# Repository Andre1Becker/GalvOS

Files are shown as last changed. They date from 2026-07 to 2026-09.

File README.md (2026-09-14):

# GalvOS








---

## What Is GalvOS?

GalvOS replaces the original control board of an RGB galvo laser projector (specifically the Mikoy 5W) with an ESP32-S3-based system. The result is a firmware platform that is more capable, fully open, and frankly more fun to work with than whatever the OEM shipped.

The origin story: the stock firmware couldn't dim the laser — it was full-brightness or nothing. What started as a quick bug investigation turned into a complete hardware and firmware replacement. Classic "Well, that escalated quickly..." moment.

**Key capabilities:**

- 16-bit galvo DAC (vs. OEM 12-bit) via SPI DAC8562
- Browser-based WebUI — no app install, works from any phone or desktop
- DMX-512, Art-Net, sACN/E1.31, and OSC input; Ether Dream and Helios (network) DAC protocols
- ILDA file playback from SD card
- Per-point laser modulation with full RGB PWM control
- BPM-synced show engine: global tempo clock (Tap/DMX/Manual), preset sequencer, and an 8-slot modulation matrix (LFO/Noise/Envelope/Step-Sequencer → any live pattern parameter)
- Watchdog, scan-command activity and E-stop interfaces — [safety qualification remains open](hardware/reviews/2026-09-14-shutdown-boundary.md)
- Point optimizer pipeline with adaptive density, S-curve blanking, and ringing compensation
- Camera-in-the-loop auto-tuning of optimizer parameters via a companion Python tool (see [Chapter 6](docs/06-camera-autotuning.md))
- Community Presets — browse, download, and activate GitHub-hosted preset bundles straight from the WebUI
- Temperature monitoring (up to 5× DS18B20 sensors)

---

## Full Feature List

Yes, all of this is real, and yes, it's all running on a 6 Freedom Money ($) microcontroller.
(That exclude all the other components you need - but hey, sounds much more impressive this way:-) )

### Output & Rendering

| Feature | What it does |
| --- | --- |
| 16-bit galvo DAC (DAC8562) | 4× the resolution of the OEM's 12-bit — lines that were jagged are now just... lines. |
| 9-stage point optimizer pipeline | Turns "draw a hexagon" into a stream the mirrors can physically survive — corner dwell, blanking, velocity/acceleration clamp, ZV ringing compensation. |
| 8 optimizer profiles (Vector, Smooth, Waves, Wireframe, MultiObject, Particles, Trails, Text) | One-size-fits-all optimizer settings don't exist, so pick per preset class instead. Auto-switches with the active preset. |
| Curvature-adaptive resampling | Spends points where the path actually bends and thins them out on straight runs, instead of pretending every millimetre is equally interesting. |
| Jump-order optimization (nearest-neighbour + 2-opt) | Reorders which segment gets drawn when, so the beam stops zigzagging across the canvas with the laser off. |
| Optimizer live telemetry | Lit/blank counts, truncated points, jump distance, which budget stage fired — tuning with numbers instead of vibes. |
| Smart Defaults button | Computes sane optimizer parameters from your kpps and frame budget. For when guessing sliders gets old. |
| Adjustable galvo sample rate (12–60 kpps) with Autotune | Binary-searches the highest rate your hardware handles before it starts buffering complaints. |
| CIE 1931 gamma correction | γ≈2.2 so "50% brightness" actually looks like 50% brightness to your eyeballs, not to a linear sensor. |
| Projection zone clipping | Draw a polygon, laser respects it. Points outside get blanked instead of redecorating your neighbor's wall. |
| Grid warp (keystone / surface correction) | Up to 5×5 control points to bend the image onto an off-axis or non-flat wall — corrects everything the projector draws, presets to ILDA files. |
| Brightness compensation grid | Same grid editor aimed at photons: evens out the exposure falloff you get from throw distance and angle. |
| Model-based inverse filter | Per-axis deconvolution of the galvo's measured resonance, applied to every point — the mirrors track the commanded path instead of ringing around it. |
| Output pre-scale | Shrinks the image proportionally so extreme corners stay in the galvo's linear range, instead of being flattened by the DAC clamp. |

### Patterns & Effects

| Feature | What it does |
| --- | --- |
| Built-in preset library (Geometry, Waves, 3D, Scenes, math curves) | A whole gallery of shapes so you don't have to parametrize a Lissajous curve at 2 AM. |
| Auto-rotation (independent X/Y/Z) + static rotation offset | Spin any pattern on any axis, at its own speed, because static geometry is for cowards. |
| 7 color animation modes (Gradient, Chase, Strobe, Pulse, Twinkle, Flip, Seg) | Layer a light show on top of any preset's own color without touching its code. |
| Points-Only Mode | Turns any pattern into a dot cloud with configurable fade-in/out and fade direction — instant particle show. |
| True Kaleidoscope (dihedral mirror-fold, 2/4/6-fold) + Radial Repeat mode & Mirror | Symmetric multiplication of whatever's on screen, because one hexagon is never enough. |
| Global BPM clock (Manual / Tap Tempo / DMX) | The whole show keeps a beat — priority DMX > Tap > Manual, with a big satisfying TAP button. |
| Preset Sequencer | A BPM-synced set list: walk presets step by step, beat-quantized, with optional blank transitions. Never auto-starts on boot — Class 4 lasers don't get autoplay. |
| Modulation engine (8 slots × 16 bindings) | LFOs, noise, multi-point envelopes, and step sequencers routed onto scale, rotation, hue, speed, density... Patterns that breathe on their own. |
| Modular modules: Camera, Duplicator, Spatial Noise, Dotter | Self-registering firmware modules that add 3D camera moves, frame cloning (grid/radial/spiral), organic wobble, and dot scatter — the UI discovers them automatically. |
| Freehand Paint tab | Draw with your finger or mouse, project it as vectors. Shape tools, mirror modes, undo/redo, and text insertion included for people who can't draw circles. |
| Laser Welding effect | A travelling torch head with a fading afterglow and ballistic sparks, rendered from the same Paint canvas. Pure theatre, and worth it. |
| SVG import | Load a vector drawing in the browser, simplify it to fit the point budget, and project it. Files can live on the SD card too. |
| Per-segment colors | Give a polygon or star a different color per edge, with an optional travelling animation. |
| Laser Text mode | 3 fonts, 10 animations (scroll, bounce, typewriter, Star Wars crawl,...), up to 127 characters. |
| Countdown timer with laser payoff | Set a timer, and when it hits zero: show text or fire off an ILDA file. Genuinely useful for events. |
| Community Presets (GitHub-hosted) | Browse a shared preset library straight from GitHub in the WebUI, download to the device, activate with one tap — each bundle carries a full optimizer tuning plus playback params. Now the internet can pick your colors too. |
| Community Preset Builder | Offline browser tool ([`community-presets/builder.html`](community-presets/builder.html)) for creating those bundles — for people who'd rather drag sliders than write C++. Advanced Mode even has a point/curve editor that exports C++ snippets for new built-in presets. |

### Control Inputs

| Feature | What it does |
| --- | --- |
| DMX-512 input (MAX485, 25 channels) | Talks to any real lighting desk like a grown-up fixture. |
| Art-Net input | DMX over Ethernet/Wi-Fi for the desk-less crowd. |
| sACN / E1.31 input | The standards-blessed way to do DMX over IP multicast. Same channel map, lowest priority of the three DMX-shaped sources. |
| OSC input | `/galvos/*` on UDP 9000 — preset, color, speed, brightness, and override from TouchOSC & friends. |
| Ether Dream protocol receiver | Laser software that speaks Ether Dream can stream point data straight to the projector. |
| Helios DAC network emulation | Helios point-stream framing over TCP 7768. The USB variant is not implemented (TinyUSB vendor class vs. the USB-CDC console). |
| Live software DMX console (WebUI) | 25 sliders, no physical desk required, with instant test patterns (red circle, rainbow). |
| WebUI override priority | WebUI wins over DMX on demand — for when you need to grab manual control mid-show. |
| Master dimmer (WebUI + DMX CH1 combined) | One dial to rule the overall brightness, regardless of source. |

### Storage & Playback

| Feature | What it does |
| --- | --- |
| ILDA file playback from SD card | Plays the industry-standard laser show format straight off a memory card — subfolders, live speed/size/color-override controls, browser upload included. |
| Playlist manager | Queue multiple ILDA files with per-entry loop count and pause duration. |
| PSRAM budget guard for ILDA files | Files too big to load safely are grayed out *before* you play them, instead of rebooting the controller mid-show. |
| SD auto-mount watcher | Insert a card whenever — it gets picked up within 5 seconds. Eject means eject, until you say otherwise. |
| SD file management from the browser | Download, rename, or delete `.ild` and `.svg` files on the card without pulling it out of the projector. |
| Independent SPI3 bus for SD | SD reads no longer corrupt the DAC output mid-frame — SD card lives on its own SPI3 bus (GPIO5/6/1/42), fully independent of the DAC's SPI2. |

### Calibration & Tuning

| Feature | What it does |
| --- | --- |
| Galvo geometry calibration | Offset, gain (linked X/Y), swap, invert — dial in a perfectly centered, correctly proportioned image. |
| Color/gamma calibration patterns | White fill, per-channel fill, three-circle white balance, crosshair, grid, DAC range box, official ILDA test pattern. |
| Visibility threshold calibration | Finds each laser diode's "dead zone" so 0–100% brightness maps to what's actually visible instead of a chunk of invisible PWM range. |
| Auto White Balance | Calculates per-channel gain from configured laser power so R/G/B actually look equally bright. |
| Camera-in-the-loop auto-tuning | A USB camera + Optuna search auto-tunes optimizer profiles against measured beam quality — no more "nudge a slider, squint at the wall" loop. See [Chapter 6](docs/06-camera-autotuning.md). |
| Resonance sweep | Drives one axis with a pure sine at a chosen frequency so you can actually measure the galvo's resonance instead of guessing at it. |

### Safety & Reliability

| Feature | What it does |
| --- | --- |
| Hardware E-Stop input | A physical kill switch the firmware cannot override. |
| NE555 scan-fail detection | If the galvo stops moving (or firmware hangs), the laser cuts — hardware-level, no software in the loop. |
| NE555 hardware watchdog | Independent of the ESP32's own watchdog; catches the case where the ESP32 itself locks up. |
| Fail-safe opto-isolated RGB TTL | 10kΩ pull-ups keep every laser channel OFF by default on boot, reset, panic, or brownout. |
| OTA update lockout while armed | Can't push new firmware to a live, armed laser. On purpose. |
| Browser OTA for firmware *and* WebUI | An `/update` page that flashes either partition, reports real error strings, and refuses to auto-reboot into a half-finished update. |
| Safety Assessment card | Live laser-class and audience-distance estimate from your configured power and beam angles. |
| Thermal protection | Up to 5× DS18B20 sensors with per-sensor names and calibration offsets, configurable warn/reduce/shutdown thresholds, auto or manual fan control, and a °C/°F/K display switch. |

### Connectivity & UI

| Feature | What it does |
| --- | --- |
| Browser-based WebUI, installable as a PWA | No app store, no native install — works full-screen from any phone, tablet, or desktop. |
| Three switchable themes | Cyberpunk/Glitch, Terminal CLI, Minimalist Dark — same controls, three personalities, zero flash-of-wrong-theme on reload. |
| Mobile-first safety controls | ARM/DISARM and Master Dimmer pinned in an always-visible top bar, 44 px touch targets — the kill switch never scrolls away. |
| Per-protocol debug logging | A "snitch switch" per network protocol (DMX, Art-Net, Ether Dream, Helios, OSC, sACN) — raw traffic straight into the Log tab. |
| Live Dashboard | Safety status, telemetry, CPU load, temperature history, DAC output rate, and frame composition — all scrolling in real time. |
| Live log console + memory viewer | Streamed over WebSocket, color-coded by severity, plus a heap/PSRAM breakdown by subsystem for hunting leaks. |
| Wi-Fi AP + STA mode, mDNS | Joins your network and answers at `galvOS.local`; falls back to its own WPA-protected access point when the network is unreachable, while still retrying in the background. |
| Static IP / DHCP configuration | For the tinfoil hatters who don't trust DHCP leases. |
| REST API with token auth | Full external control surface — see [API Reference](docs/08-api-reference.md). |
| Factory reset | Nukes all NVS config back to defaults when you've fat-fingered one setting too many. |

---

## Quick Start

Feeling yolo? Take this route then:

1. **Read the [Safety section](docs/01-introduction.md#safety--read-this-first)** — seriously.
2. **Check [Prerequisites](docs/02-prerequisites.md)** — tools and hardware needed.
3. **[Build & Flash](docs/03-build-and-config.md)** — PlatformIO build, firmware + WebUI upload.
4. **[Connect to WebUI](docs/04-ui-guide.md)** — Wi-Fi, browser, done.

No board on the bench yet? Try the WebUI first at **[www.galvos.de](https://www.galvos.de)** — see [Live Simulator](#live-simulator-no-hardware-required) below.

---

## Live Simulator (No Hardware Required)

**[www.galvos.de](https://www.galvos.de)** runs the exact WebUI as a self-contained browser simulation — a fake firmware backend behind the same frontend, no ESP32, no flashing, no install. Click around every tab, fire presets, tune the optimizer, and watch a simulated galvo trace respond, all before you own a single component. Handy for evaluating the UI, planning a build, or just seeing what the fuss is about.

It is **not** identical to a real device — no camera-in-the-loop tuning, no actual laser/galvo output, and it can lag a patch or two behind the firmware/UI shipped here (maintained by hand, see [Known Issues](docs/10-known-issues-and-todos.md#ui-issues)). For the real thing, [build one](docs/03-build-and-config.md).

---

## Documentation

Need a good sleep aid? This is the one for you here:

| Chapter | Description |
| --- | --- |
| [01 — Introduction](docs/01-introduction.md) | Project background, safety, disclaimer, hardware overview |
| [02 — Prerequisites](docs/02-prerequisites.md) | Tools, hardware, software, and skills needed |
| [03 — Build & Configuration](docs/03-build-and-config.md) | PlatformIO setup, all configurable parameters, flash instructions |
| [04 — UI Guide](docs/04-ui-guide.md) | Complete walkthrough of all WebUI tabs and controls |
| [05 — The Optimizer](docs/05-optimizer.md) | Deep-dive into the point optimizer pipeline |
| [06 — Auto-Tuning (CAM-based)](docs/06-camera-autotuning.md) | Automated optimizer tuning via `scripts/optimizeGalvo/optimizeGalvo.py` and a USB camera |
| [07 — Troubleshooting](docs/07-troubleshooting.md) | Common problems and how to solve them |
| [08 — API Reference](docs/08-api-reference.md) | REST API endpoints for integration and automation |
| [09 — Contributing](docs/09-contributing.md) | How to contribute, code style, patch workflow |
| [10 — Known Issues & To-dos](docs/10-known-issues-and-todos.md) | Open bugs, missing features, planned work |
| [11 — Glossary & Terminology](docs/11-glossary.md) | All (no but most) abbreviations and technical terms explained |

Release history: [CHANGELOG.md](CHANGELOG.md).

---

## Hardware at a Glance

Don't like one's and zero's that much? Well, this one is for you then:

| Component | Part |
| --- | --- |
| MCU | ESP32-S3-WROOM-1 N16R8 (16 MB Flash, 8 MB OPI PSRAM) |
| DAC | DAC8562 (16-bit, dual-channel, SPI) |
| Output Stage | OPA4134UA quad op-amp — differential ±5V galvo drive |
| Galvo Set | Jolooyo JY-15K-BL (15 kpps, ±20° optical) |
| Laser Driver | MN-1M5AT (3-channel constant-current buck, active-HIGH) |
| DMX | MAX485 module (receive-only, XLR) |
| Safety | NE555 scan-fail + NE555 hardware watchdog, 6N137 optocouplers |
| Temperature | DS18B20 × up to 5, 1-Wire bus |
| Power | HW-613 buck converter (+5V rail); external ±15V galvo PSU |
| Construction | Perfboard 15 × 9 cm; Gerber File for custom PCB is in progress |

Full netlist: [`hardware/`](hardware/)

---

## Repository Structure

```text
GalvOS/
├── src/                    # Firmware source (C++, Arduino/PlatformIO)
│   ├── control/            # DMX, Art-Net, safety control
│   ├── ilda/               # ILDA file parser
│   ├── net/                # WebUI server, REST API, Art-Net/sACN/OSC/Ether Dream/Helios receivers
│   ├── output/             # Galvo ISR, DAC output, RGB PWM
│   ├── patterns/           # Pattern engine, presets, optimizer
│   ├── safety/             # E-Stop, watchdog, scan-fail
│   ├── sensors/            # DS18B20, temperature monitoring
│   ├── storage/            # SD card, ILDA playlists, SVG storage
│   └── util/               # Shared utilities (log buffer, CPU/mem monitors, PSRAM scratch)
├── include/
│   ├── config.h            # Runtime config struct, optimizer defaults
│   └── pinmap.h            # All GPIO assignments
├── data/
│   └── index.html          # WebUI (single-file PWA, served via LittleFS)
├── community-presets/      # GitHub-hosted community preset library
│   ├── index.json          # Preset index fetched by the WebUI's GitHub Browser
│   ├── builder.html        # Community Preset Builder (offline browser tool, no backend)
│   └── *.json              # The preset bundles themselves
├── test/                   # Host-side (native) test suites
├── hardware/               # Netlist, schematics, wiring diagrams
├── scripts/
│   ├── upload_all.py       # PlatformIO target: flash firmware + LittleFS
│   ├── gzip_assets.py      # Pre-build hook: gzip data/ assets
│   ├── test_protocols.py   # Manual Ether Dream/Helios stream test client
│   └── optimizeGalvo/      # Camera-in-the-loop auto-tuning tool (see docs/06)
├── docs/                   # Full documentation (you are here)
│   ├── index.html          # Standalone WebUI simulator (served at galvos.de, no backend)
│   └── assets/             # Screenshots, diagrams, photos
├── platformio.ini          # Build configuration
└── partitions.csv          # Flash partition table
```

---

## ⚠️ SAFETY WARNING — READ BEFORE PROCEEDING

(I know - BORING! But hey - at least you read this far. So keep going!)

**This project involves CLASS IIIB or CLASS IV laser devices.**

Lasers at these power levels are capable of causing **immediate and permanent eye injury** and skin burns, and can ignite materials at close range.

- **Never** look into the beam or at specular (mirror-like) reflections.
- **Always** use appropriate laser safety eyewear — OD rating matched to your specific wavelengths and power level.
- **Never** operate the laser without proper enclosure or beam stops in place.
- By modifying this device, the original CE marking and safety certification are **void**.
- **You are solely responsible** for the safe operation of any device built using this project.
- Check your local laws — modifying laser equipment may require licensing in your jurisdiction.

> 🔴 **This project is intended for experienced makers and engineers who understand laser safety. Treat every beam as dangerous until proven otherwise.**

---

## License

- **Firmware & Software:** [GNU General Public License v3.0](LICENSE)
- **Hardware Designs:** [CERN Open Hardware License v2 — Strongly Reciprocal (CERN-OHL-S)](https://ohwr.org/cern_ohl_s_v2.txt)

Contributions welcome under the same license terms. See [Contributing](docs/09-contributing.md).

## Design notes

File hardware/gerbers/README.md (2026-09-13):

# Historical fabrication files — do not order as v2

These files predate the current v2 production-readiness work. Their match to
`Laser Controllerv2_only_for_pcb_test.kicad_sch` has not been established.
The current legacy PCB also fails fresh DRC. Keep these files for history;
generate and review a new release only after the schematic, PCB and production
checks are complete. See [work log](../../codex-todos.md) and
[current audit](../reviews/2026-09-13-v2-audit.md).

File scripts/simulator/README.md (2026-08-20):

# GalvOS Browser Simulator

`docs/index.html` (published at <https://www.galvos.de>) is a **generated file**.
Do not edit it by hand — it is `data/index.html` plus the thin simulator layer
in this folder, assembled by `build_simulator.py`.

| File | Role |
| ---- | ---- |
| `build_simulator.py` | Assembles `docs/index.html` from WebUI + this layer |
| `sim_engine.js` | Preset engine, simplified optimizer, mock `/api/*` backend |
| `overlay.html` | Launch/disclaimer card, shown once per session |
| `check_simulator.py` | Headless-Chrome smoke test of the generated page |

## Why generated

The simulator *is* the WebUI: same markup, same CSS, same JS bundle, so every
tab, slider and endpoint behaves like the real device without a board attached.
Maintaining it as a fork meant re-reviewing a 6000-line diff after every UI
change; as a transform, re-syncing is a rerun.

## Re-syncing after a WebUI or firmware change

```bash
# 1. bump the identity block at the top of sim_engine.js:
#    SIM_UI_VERSION  -> data/index.html's UI_VERSION      (always)
#    FW_VERSION      -> platformio.ini's LASER_FW_VERSION (always)
#    FW_COMMIT       -> git rev-parse --short HEAD        (always)
#    SIM_VERSION     -> bump when the sim layer itself changed
# 2. regenerate
.venv/Scripts/python.exe scripts/simulator/build_simulator.py
# 3. verify (fails on any page error)
.venv/Scripts/python.exe scripts/simulator/check_simulator.py
```

`build_simulator.py` refuses to run if `sim_engine.js`'s `FW_VERSION` /
`SIM_UI_VERSION` disagree with `platformio.ini` / `data/index.html`, and if any
of its markup anchors in `data/index.html` no longer match exactly once.

## Scope of the simulation

Ported faithfully (kept in sync with the firmware sources):

- all 81 presets and their live parameters
- interior density, corner dwell, distance-proportional blank jumps and the
  frame-budget squeeze, per optimizer profile (`OPT_PROFILE_DEFAULTS`)
- `presetClassOf()`'s preset → profile mapping
- rotation, mirror, both kaleidoscope modes, points-only mode, autoscale,
  per-side colors, color override, master dimmer
- wall-clock animation phase (`kAnimPhaseFrameMs`), so presets animate at
  device speed regardless of the browser's frame rate
- `/api/state`, `/api/config` (including all 8 optimizer profiles and their
  effective PPS-scaled values), `/api/optimizer-stats` measured off the frame
  actually rendered, plus the warp/brightness/weld/seg-color/text/paint/zone/
  timer/modulator endpoints
- Text Mode (all 3 fonts, all 11 animations, rainbow/flip) and Paint by
  Finger both actually drive the beam preview, matching pattern_engine.cpp's
  source priority (Text > Paint > Preset) -- not just mocked as API state
- Laser Welding (weld_path.h/weld_patterns.cpp): the torch/afterglow/spark
  effect over either source's path, including direction (Fwd/Rev/Ping-Pong)
  and the Reverse seek-to-end behavior

Deliberately not simulated: SD card, ILDA/SVG playback, DMX/Art-Net input, OTA,
arming (refused, there is no hardware), the ZV ringing shaper's sample-level
trajectory, the Dotter, and BPM-synced modulator output.

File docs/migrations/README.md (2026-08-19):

# Config Migrations

Full-device config snapshots (`/api/backup` format) taken around changes that
alter how stored values are interpreted. Restore one with the Configuration
tab's **Restore** button, or:

```bash
curl -X POST -H "Content-Type: application/json" \
     --data-binary @<file>.json http://<device>/api/restore
```

The device validates every value before applying anything, then reboots. A
single rejected key aborts the whole restore untouched.

---

## 2026-08-19 — `galvo_rated_kpps` 45 → 15 (fw v6.79.0)

| File | Contents |
| --- | --- |
| `2026-08-19-rated-kpps-45-rollback.json` | State **before** the migration (`rated_kpps: 45`). Restore this to undo. |
| `2026-08-19-rated-kpps-15-applied.json` | State **after** (`rated_kpps: 15`, profiles rescaled). |

### Why

`galvo_rated_kpps` held 45 while the JY-15K-BL's datasheet figure — and the
firmware default in `config.h` — is 15. The field is the anchor for
`applyPpsScaling()`, so the wrong anchor meant every **community preset**
(which ships raw optimizer values with no anchor of its own, see
`community_presets.cpp`) was interpreted with `r` 3× too large: density 3× too
low, velocity ceiling 3× too permissive, acceleration ceiling 9× too permissive.

### What was done

The rescale factor is `k = rated_old / rated_new = 3`, and the output rate
**cancels out** — so this is an exact change of units, not a re-tune. With
`effective = raw × r^e`, holding `effective` constant requires
`raw_new = raw_old × k^e`:

| Field | `e` | Factor |
| --- | --- | --- |
| `pts_per_1000_units` | −1 | ÷3 |
| `blank_pts_per_1000_units` | −1 | ÷3 |
| `resample_spacing_units` | +1 | ×3 |
| `min_spacing_units` | +1 | ×3 |
| `max_spacing_units` | +1 | ×3 |
| `max_step_units` | +1 | ×3 |
| `max_accel_units` | +2 | ×9 |

Verified across all 8 profiles: zero values saturate their firmware
`constrain()` bounds, and effective values are preserved to 1.25e-06 relative
(float rounding only).

### Firmware changes shipped alongside

Both were needed because they depended on the old anchor and would have broken
on their own:

- `text_renderer.cpp` — the per-glyph density constant `K` was scaled by
  `1/ppsRatio(rated, output)`, silently tying an absolute empirical calibration
  to the anchor. At the new anchor that tripled text density, straight back into
  the documented "only ~8 chars render" bug. Now scaled against
  `TEXT_DENSITY_REF_KPPS`, making it anchor-independent.
- `data/index.html` — the exit-angle warning compared the DAC sample clock
  against the mechanical ILDA derating (`15 × 8/20 = 6` kpps) and would have
  been pinned on permanently. Replaced with an informational line; the same
  category error the sample-rate autotune used to make.

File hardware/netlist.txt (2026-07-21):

================================================================================
  galvOS LASER CONTROLLER v3.2 — WIRING NETLIST
  ESP32-S3-WROOM-1 N16R8
================================================================================

── SUPPLY +5V_BUCK ─────────────────────────────────────────────────────────────
Laser PSU DC              -> D1 1N5819 Anode
D1 1N5819 Cathode         -> Buck-Converter IN+
Buck-Converter GND        -> GND
Buck-Converter OUT+       -> +5V_BUCK (main rail)
+5V_BUCK                  -> C_BULK 100µF [Electrolytic: +] -> GND
+5V_BUCK                  -> C_HF   100nF [Ceramic]         -> GND
+5V_BUCK                  -> U1 ESP32-S3 J1-Pin21 (VIN)
+5V_BUCK                  -> U2 DAC8562 Pin9 (AVDD)
+5V_BUCK                  -> MAX485 Module VCC
+5V_BUCK                  -> U11 NE555 Pin8 (VCC)
+5V_BUCK                  -> U12 NE555 Pin8 (VCC)
+5V_BUCK                  -> SSR1 IN+ (via R_EN 1kΩ from GPIO38)
+5V_BUCK                  -> U_6N_R Pin8 (VCC)
+5V_BUCK                  -> U_6N_G Pin8 (VCC)
+5V_BUCK                  -> U_6N_B Pin8 (VCC)
+5V_BUCK                  -> U_6N_R Pin7 (VE)
+5V_BUCK                  -> U_6N_G Pin7 (VE)
+5V_BUCK                  -> U_6N_B Pin7 (VE)
+5V_BUCK                  -> R_PU_R 1kΩ -> U_6N_R Pin6 (Vo)
+5V_BUCK                  -> R_PU_G 1kΩ -> U_6N_G Pin6 (Vo)
+5V_BUCK                  -> R_PU_B 1kΩ -> U_6N_B Pin6 (Vo)
+5V_BUCK                  -> U2 DAC8562 Pin5 /CLR via R_CLR 10kΩ

── SUPPLY +3.3V (ESP32 internal regulator) ─────────────────────────────────────
U1 ESP32-S3 J1-Pin1       -> +3V3
U1 ESP32-S3 J1-Pin2       -> +3V3
+3V3                       -> C 10µF  [Electrolytic: +] -> GND
+3V3                       -> C 100nF [Ceramic]         -> GND
+3V3                       -> R_ESTOP 10kΩ -> J_ESTOP Pin1
+3V3                       -> R_1W 4.7kΩ   -> J_1W Pin2 (Data)

── SUPPLY ±15V (Galvo PSU direct) ─────────────────────────────────────────────
Galvo PSU +15V             -> C 100µF [Electrolytic: +] -> AGND
Galvo PSU +15V             -> C 100nF [Ceramic]         -> AGND
Galvo PSU +15V             -> U_OPA OPA4134 Pin4 (V+)
Galvo PSU -15V             -> C 100µF [Electrolytic: -] (+ to AGND)
Galvo PSU -15V             -> C 100nF [Ceramic]         -> AGND
Galvo PSU -15V             -> U_OPA OPA4134 Pin11 (V-)

── GROUND ───────────────────────────────────────────────────────────────────────
U1 ESP32-S3 J1-Pin22       -> GND
U1 ESP32-S3 J2-Pin1        -> GND
U1 ESP32-S3 J2-Pin21       -> GND
U1 ESP32-S3 J2-Pin22       -> GND
U2 DAC8562 Pin3            -> AGND
MAX485 Module GND          -> GND
U11 NE555 Pin1             -> GND
U12 NE555 Pin1             -> GND
U_6N_R Pin5 (GND)          -> GND
U_6N_G Pin5 (GND)          -> GND
U_6N_B Pin5 (GND)          -> GND
SSR1 IN-                   -> GND
AGND <-> GND               -> 0Ω star point (next to U2 DAC8562)

── SPI BUS (DAC8562, SPI2 -- exclusive, no longer shared) ──────────────────────
U1 ESP32-S3 J1-Pin18 GPIO12 -> U2 DAC8562 Pin7 (SCLK)
U1 ESP32-S3 J1-Pin17 GPIO11 -> U2 DAC8562 Pin8 (DIN)
U1 ESP32-S3 J1-Pin16 GPIO10 -> U2 DAC8562 Pin6 /SYNC (CS)
U2 DAC8562 Pin4 (/LDAC)     -> AGND

── SPI BUS (SD Card, SPI3 -- independent bus, own GPIOs) ───────────────────────
-- REWIRE PENDING (fw v5.90.0): moved off GPIO12/11/2/9 (was silently stealing
-- the DAC's SCLK/DIN pins via the GPIO matrix whenever SD.begin() ran -- root
-- cause of "galvo goes erratic when a card is inserted"). Move these 4 wires:
U1 ESP32-S3 J1-Pin5  GPIO5  -> J_SD Pin3 (SCK)
U1 ESP32-S3 J1-Pin6  GPIO6  -> J_SD Pin2 (MOSI)
U1 ESP32-S3 J2-Pin4  GPIO1  -> J_SD Pin1 (MISO)
U1 ESP32-S3 J2-Pin6  GPIO42 -> J_SD Pin4 (CS)

── DAC8562 VREF + OPA4134 VREF BUFFER ──────────────────────────────────────────
U2 DAC8562 Pin10 (VREFOUT)  -> C_vr 100nF [Ceramic] -> AGND
U2 DAC8562 Pin10 (VREFOUT)  -> U_OPA OPA4134 Pin10 (3IN+)
U_OPA OPA4134 Pin9  (3IN-)  -> U_OPA OPA4134 Pin8 (3OUT)
U_OPA OPA4134 Pin8  (3OUT)  -> C_REF 100nF [Ceramic] -> AGND
U_OPA OPA4134 Pin8  (3OUT)  -> VREF_BUF (2.5V net)

── GALVO SIGNAL PATH X (differential amplifier, VOUT = 2×(2.5V − VDAC)) ────────
U2 DAC8562 Pin1 (VOUTA)     -> R_X1 100Ω -> Node_X
Node_X                      -> C_X 1nF [Ceramic] -> AGND
Node_X                      -> R1_X 10kΩ -> U_OPA OPA4134 Pin2 (1IN-)
U_OPA OPA4134 Pin1 (1OUT)   -> R2_X 22kΩ -> U_OPA OPA4134 Pin2 (1IN-)
VREF_BUF                    -> R3_X 10kΩ -> U_OPA OPA4134 Pin3 (1IN+)
U_OPA OPA4134 Pin3 (1IN+)   -> R4_X 22kΩ -> AGND
U_OPA OPA4134 Pin1 (1OUT)   -> R_XO 100Ω -> J_GALVO Pin2 (XIN)

── GALVO SIGNAL PATH Y (differential amplifier) ────────────────────────────────
U2 DAC8562 Pin2 (VOUTB)     -> R_Y1 100Ω -> Node_Y
Node_Y                      -> C_Y 1nF [Ceramic] -> AGND
Node_Y                      -> R1_Y 10kΩ -> U_OPA OPA4134 Pin6 (2IN-)
U_OPA OPA4134 Pin7 (2OUT)   -> R2_Y 22kΩ -> U_OPA OPA4134 Pin6 (2IN-)
VREF_BUF                    -> R3_Y 10kΩ -> U_OPA OPA4134 Pin5 (2IN+)
U_OPA OPA4134 Pin5 (2IN+)   -> R4_Y 22kΩ -> AGND
U_OPA OPA4134 Pin7 (2OUT)   -> R_YO 100Ω -> J_GALVO Pin4 (YIN)

── OPA4134 CHANNEL 4 (unused, secured) ─────────────────────────────────────────
U_OPA OPA4134 Pin12 (4IN+)  -> AGND
U_OPA OPA4134 Pin13 (4IN-)  -> U_OPA OPA4134 Pin14 (4OUT)

── GALVO CONNECTOR ─────────────────────────────────────────────────────────────
J_GALVO Pin1 (PXY)          -> NC
J_GALVO Pin2 (XIN)          -> from R_XO (see Galvo X)
J_GALVO Pin3 (GND)          -> AGND
J_GALVO Pin4 (YIN)          -> from R_YO (see Galvo Y)

── LASER ENABLE (SSR) ──────────────────────────────────────────────────────────
U1 ESP32-S3 J2-Pin10 GPIO38 -> R_EN 1kΩ    -> SSR1 IN+
U1 ESP32-S3 J2-Pin10 GPIO38 -> R_PD_EN 10kΩ -> GND
SSR1 IN-                    -> GND

── LASER TTL R/G/B (via 6N137) ─────────────────────────────────────────────────
U1 ESP32-S3 J1-Pin7  GPIO7  -> R_R 220Ω -> U_6N_R Pin2 (Anode)
U1 ESP32-S3 J1-Pin12 GPIO8  -> R_G 220Ω -> U_6N_G Pin2 (Anode)
U1 ESP32-S3 J2-Pin18 GPIO21 -> R_B 220Ω -> U_6N_B Pin2 (Anode)
U_6N_R Pin3 (Cathode)       -> GND
U_6N_G Pin3 (Cathode)       -> GND
U_6N_B Pin3 (Cathode)       -> GND
U_6N_R Pin6 (Vo)            -> J_LASER Pin1 (R_TTL)
U_6N_G Pin6 (Vo)            -> J_LASER Pin3 (G_TTL)
U_6N_B Pin6 (Vo)            -> J_LASER Pin5 (B_TTL)
J_LASER Pin2                -> GND
J_LASER Pin4                -> GND
J_LASER Pin6                -> GND
U_6N_R Pin1, Pin4           -> NC
U_6N_G Pin1, Pin4           -> NC
U_6N_B Pin1, Pin4           -> NC
U_6N_R Pin8 VCC, Pin7 VE    -> +5V_BUCK
U_6N_G Pin8 VCC, Pin7 VE    -> +5V_BUCK
U_6N_B Pin8 VCC, Pin7 VE    -> +5V_BUCK
U_6N_R Pin8/Pin5            -> C 100nF [Ceramic, direct] -> GND
U_6N_G Pin8/Pin5            -> C 100nF [Ceramic, direct] -> GND
U_6N_B Pin8/Pin5            -> C 100nF [Ceramic, direct] -> GND

── DMX (MAX485 Module) ─────────────────────────────────────────────────────────
J_DMX XLR Pin1 (Shield)     -> GND
J_DMX XLR Pin2 (D-)         -> MAX485 Module B
J_DMX XLR Pin3 (D+)         -> MAX485 Module A
MAX485 Module DE             -> GND
MAX485 Module RE             -> GND
MAX485 Module VCC            -> +5V_BUCK
MAX485 Module GND            -> GND
MAX485 Module RO             -> U1 ESP32-S3 J1-Pin4 GPIO4

── NE555 SCAN-FAIL ─────────────────────────────────────────────────────────────
U2 DAC8562 Pin1 (VOUTA)     -> C_AC 100nF [Ceramic] -> U11 NE555 Pin2 (TRIG)
U11 NE555 Pin8 (VCC)        -> R_T 100kΩ -> U11 NE555 Pin7 (DIS)
U11 NE555 Pin6 (THR)        -> U11 NE555 Pin7 (DIS)
U11 NE555 Pin7 (DIS)        -> C_T 10µF [Electrolytic: +] -> GND
U11 NE555 Pin4 (RST)        -> +5V_BUCK
U11 NE555 Pin5 (CTRL)       -> C 100nF [Ceramic] -> GND
U11 NE555 Pin3 (OUT)        -> U1 ESP32-S3 J2-Pin9 GPIO39

── NE555 HARDWARE WATCHDOG ─────────────────────────────────────────────────────
U1 ESP32-S3 J1-Pin20 GPIO14 -> R_HB 1kΩ           -> U12 NE555 Pin2 (TRIG)
U12 NE555 Pin8 (VCC)        -> R_W1 10kΩ           -> U12 NE555 Pin7 (DIS)
U12 NE555 Pin7 (DIS)        -> R_W2 Trimmer 50kΩ   -> U12 NE555 Pin6 (THR)
U12 NE555 Pin6 (THR)        -> C_W 100µF [Electrolytic: +] -> GND
U12 NE555 Pin4 (RST)        -> +5V_BUCK
U12 NE555 Pin5 (CTRL)       -> C 100nF [Ceramic] -> GND
U12 NE555 Pin3 (OUT)        -> WD Relay Control -> SSR1 Enable Path

── EMERGENCY STOP ───────────────────────────────────────────────────────────────
J_ESTOP Pin1                -> U1 ESP32-S3 J2-Pin17 GPIO47
J_ESTOP Pin2                -> GND

── ENCODER ─────────────────────────────────────────────────────────────────────
REMOVED in v3.2 (GPIO15, GPIO40, GPIO41 free)

── FAN ──────────────────────────────────────────────────────────────────────────
U1 ESP32-S3 J1-Pin9  GPIO16 -> R 100Ω -> J_FAN1 Pin1 (PWM)
U1 ESP32-S3 J1-Pin10 GPIO17 -> R 100Ω -> J_FAN2 Pin1 (PWM)
J_FAN1 Pin2                 -> GND
J_FAN2 Pin2                 -> GND

── TEMPERATURE SENSOR (1-Wire) ─────────────────────────────────────────────────
J_1W Pin1 (VCC)             -> +3V3
J_1W Pin2 (Data)            -> U1 ESP32-S3 J1-Pin11 GPIO18
J_1W Pin3 (GND)             -> GND

── DEBUG UART ──────────────────────────────────────────────────────────────────
U1 ESP32-S3 J2-Pin2 GPIO43  -> J_UART Pin1 (TX)
U1 ESP32-S3 J2-Pin3 GPIO44  -> J_UART Pin2 (RX)
J_UART Pin3                 -> +3V3
J_UART Pin4                 -> GND

── SD CARD ──────────────────────────────────────────────────────────────────────
J_SD Pin5 (VCC)             -> +3V3
J_SD Pin6 (GND)             -> GND

================================================================================
  RESISTOR SUMMARY
================================================================================
220Ω × 3   6N137 input series resistor Laser R/G/B
1kΩ  × 3   6N137 output pull-up R/G/B
1kΩ  × 3   6N137 output pull-down R/G/B
1kΩ  × 1   SSR1 series resistor
1kΩ  × 1   NE555 Watchdog trigger
10kΩ × 1   SSR1 pull-down GPIO38
10kΩ × 1   DAC8562 /CLR pull-up
10kΩ × 1   E-Stop pull-up
4.7kΩ× 1   1-Wire pull-up
100kΩ× 1   NE555 Scan-Fail timing
10kΩ + Trimmer 50kΩ × 1   NE555 Watchdog timing
10kΩ × 4   OPA4134 differential R1/R3 (1% metal film)
22kΩ × 4   OPA4134 differential R2/R4 (1% metal film)
100Ω × 5   RC filter + output protection Galvo
100Ω × 2   Fan PWM

================================================================================
  CAPACITOR SUMMARY
================================================================================
100µF  Elec.  +→+5V_BUCK    Buck bulk
100µF  Elec.  +→Pin7        NE555 Watchdog timing
10µF   Elec.  +→Pin7        NE555 Scan-Fail timing
10µF   Elec.  +→+3V3        ESP32 decoupling
10µF   Elec.  +→Pin4        OPA4134 V+ bulk
10µF   Elec.  +→AGND−→Pin11 OPA4134 V- bulk
100nF  Cer.   ×11            Decoupling caps (3× direct 6N137 VCC/GND)
100nF  Cer.   ×1             DAC8562 VREF pin (Pin10)
100nF  Cer.   ×1             AC coupling Scan-Fail
1nF    Cer.   ×2             RC filter Galvo X/Y

================================================================================
NETLIST END — galvOS Laser Controller v3.2
================================================================================

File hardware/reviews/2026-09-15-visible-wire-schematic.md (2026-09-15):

# Visible-wire schematic review — 2026-09-15

## Result

The A1 snapshot is a documentation-only copy of GalvOS V2.0.10. All 67
multi-pin signal nets are represented by continuous orthogonal wires. Signal
net labels are hidden and are used only to preserve KiCad net names. Visible
Reference and Value fields are horizontal, standardized above/below their
symbols, and clear of visible wires.

The canonical schematic, canonical PDF, PCB, KiCad project, and firmware were
not modified. The PCB does not require an update because the copied schematic
has exactly the same components and pin-to-net membership as the canonical
schematic; native PCB schematic-parity reports zero issues.

## Evidence

- Snapshot schematic SHA-256:
  `b6a2cf3082400402ab856ecf88aaa09c5aa5256373f284cadedcfd335a43d1d5`
- Snapshot PDF SHA-256:
  `ce7178ca895a54b95507c1e4290379fac4a28d112b430bf3a07408eb43afef7c`
- PDF: one A1 landscape page, `2383.92 x 1683.79 pt`.
- Electrical preservation: PASS; exactly 122 components and 110 nets, with
  identical libraries and pin membership.
- Visible connectivity: PASS; 67 signal nets, 95 wire graphs, 47 junctions,
  and 77 hidden labels. There are no visible signal labels or bus objects.
- Presentation profile: PASS; A1, 1.27 mm grid, orthogonal wires, horizontal
  fields, no wire/Reference/Value collisions, five functional regions, and
  the principal left-to-right chains.
- KiCad ERC at all severities: PASS; 0 violations.
- Hardware unit tests: PASS; 107 tests.
- Interface checks: PASS; fan power, sensors/fans, DAC, scan status, DMX,
  buck, and trigger diodes (7/7).
- PCB DRC/parity: PASS; 0 unconnected items and 0 schematic-parity issues.
  One existing `U_BUCK1` footprint-type warning remains documented and was
  not excluded or downgraded.
- PCB layout guards: PASS; DAC source routes are 2.796–6.352 mm without vias,
  and both buck-input VIN/GND paths are 6.905 mm.
- Immutable SHA-256 lock: PASS for the canonical schematic, canonical PDF,
  PCB, and KiCad project.

## Mirrored KiCad project context

The preservation netlist and ERC evidence were generated with the copied
schematic placed under its canonical basename in a temporary mirror of the
project context:

```sh
proof_dir=/tmp/galvos-visible-wires.ZPyrPg
context="$proof_dir/final-context"
copy_sch='hardware/snapshots/2026-09-15-visible-wires/Laser Controllerv2_only_for_pcb_test.kicad_sch'

cp "$copy_sch" "$context/Laser Controllerv2_only_for_pcb_test.kicad_sch"
cp 'hardware/schematics/Laser Controllerv2_only_for_pcb_test.kicad_pro' "$context/"
cp 'hardware/schematics/Laser Controllerv2_only_for_pcb_test.kicad_prl' "$context/"
cp hardware/schematics/sym-lib-table hardware/schematics/fp-lib-table "$context/"
ln -sfn "$PWD/hardware/schematics/libraries" "$context/libraries"

kicad-cli sch export netlist --format kicadxml \
  -o "$proof_dir/final.xml" \
  "$context/Laser Controllerv2_only_for_pcb_test.kicad_sch"
kicad-cli sch erc --format json --severity-all --exit-code-violations \
  -o "$proof_dir/final-erc.json" \
  "$context/Laser Controllerv2_only_for_pcb_test.kicad_sch"
```

A direct export from the snapshot directory is not used for the electrical
identity claim: without the project basename and library context, KiCad emits
different sheet/library URIs and netclass metadata even when the electrical
pin membership is unchanged.

## Visual inspection at 240 dpi

| Region | Result | Observation |
|---|---|---|
| Power | PASS | Supply chain is separated above the signal sections; rails flow down toward consumers. |
| MCU / storage / sensors / DMX / fans | PASS | Inputs are left, MCU central, fan outputs right; parallel lanes remain distinguishable. |
| DAC / analogue galvo | PASS | DAC, translator, amplifier, and galvo output read left-to-right; fields do not cross wires. |
| RGB | PASS | Three repeated channels are vertically aligned with visible, separate signal paths. |
| E-stop / watchdog / scan-fail / SSR | PASS | Safety-related blocks are grouped along the lower row and their visible branches remain traceable. |

## Scope and non-claims

This copy does not update the PCB or fabrication data. It is not a fabrication
release, safety qualification, laser-operation approval, or production
approval. It does not add or imply a separate SSR restart-interlock design.

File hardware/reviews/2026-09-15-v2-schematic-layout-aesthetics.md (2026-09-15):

# V2.0.10 schematic layout-aesthetics review

Date: 2026-09-15
Tool: KiCad 10.0.6
Scope: canonical schematic drawing only

## Result

The canonical V2.0.10 schematic was redrawn as a single-sheet engineering
drawing with five functional rows. Signal sources are on the left, processing
is central, outputs are on the right, and supply/return symbols are placed
above/below their loads. This is a drawing-only revision: the XML netlist still
contains exactly 122 components and 110 nets with identical component
properties, library data, pin membership and net names.

The result is still an **engineering draft, not approved for fabrication or
laser operation**. The separate SSR-only restart-interlock design was not
implemented or implied by this work.

## Artifact identity

| Artifact | Baseline SHA-256 | Final SHA-256 |
|---|---|---|
| Canonical schematic | `8c1796266cc1843ee5e76cb9ab3a1025354a36771a9495bd96aa1e50c6ad0cc5` | `4f36655a3db6b5c36ef65a4722ed1f9eb7d4c4fcdeb77973966a9bf6b506f086` |
| Schematic PDF | `bbfc5fb4335a76f11f08f506cf9931459e7073332e4c70010572443b0927156e` | `c4b863705803ee55f5cea0628ce073e603d91b3b57d3fccb38cf3b6bce4ad9d6` |
| Canonical PCB | `b8111d778abc5b57ec3adb1bbc94060598fb87cc0d16e584e53e28c0bce4f47a` | unchanged |
| KiCad project | `dc77f4155067018d81c509e667ad67642031a5cf69abe7181144c19c11bd3b1b` | unchanged |

The baseline is commit `d4cf341`. The final PDF was exported directly from the
canonical schematic, without an export-only formatting copy.

## Presentation changes

| Functional row | Left / input | Centre / processing | Right / output |
|---|---|---|---|
| Power | J2/J3/J4/J6 | D2, input filtering, U_BUCK1 and feedback | L1, output filtering and distributed rails |
| I/O | SD, DMX and five temperature inputs | U_DMXLV1 and U1 | two fan PWM/tach connectors |
| Analogue | four 3.3 V DAC controls | U_DACLV1, U2 and U12 | U13 galvo output |
| Laser | U1 RGB controls and pull-ups | three parallel U15/U16/U17 lanes | U4/U5/U3 outputs |
| Safety | E-stop and monitored inputs | watchdog, scan timer and status buffer | SSR and MCU-status boundaries |

Long cross-sheet conductors were replaced with exact-name labels and compact
power symbols. Internal generated `Net-(...)` labels remain exact and use a
reduced text size so they do not dominate the drawing. No bus objects were
introduced.

Source-level wire metrics changed from 329 wire objects, including 91 segments
longer than 20 mm and a 170.18 mm maximum, to 208 local stubs with a 3.81 mm
maximum and zero segments longer than 20 mm. The final sheet contains 151 local
labels and 71 global labels. Three embedded reference images, two decorative
rectangles and their redundant connector annotations were removed.

All component anchors, label anchors, no-connect markers and wire vertices are
on the 1.27 mm grid. Visible Reference and Value fields are horizontal and
mechanically standardized. The principal chains checked left-to-right are DMX,
DAC, all three laser channels and the buck path.

## Visual inspection

The complete PDF and 240 dpi crops were inspected across all five rows. Rotated
passive Reference/Value fields now render horizontally above/below the device,
and the U15/U16/U17 Reference/Value, pin and power annotations are separated.
No ambiguous long-wire crossing remains. The dense custom symbols `U_DACLV1`,
`U2` and `U12` retain library-generated internal pin text and nearby
power-annotation density; this review does not claim those library-owned pin
texts are collision-free because they cannot be moved independently without
changing the symbol libraries. Exact generated internal net labels are
deliberately rendered at 0.508 mm: they remain visible but only as a secondary
implementation detail.

## Verification evidence

| Gate | Result |
|---|---|
| XML electrical-preservation comparison | PASS — 122 components, 110 nets |
| Full presentation contract | PASS — all five blocks |
| Native schematic ERC, all severities | PASS — 0 violations |
| Fan-power, sensor/fan, DAC, scan, DMX, buck and trigger-diode interfaces | PASS — 7/7 |
| Hardware unit tests | PASS — 69 tests |
| Native PCB DRC with refill and schematic parity | 0 unconnected, 0 parity, 1 known warning |
| PCB draft-evidence guard | PASS |
| DAC source-layout guard | PASS — 2.796–6.352 mm source paths, no vias |
| Buck input-layout guard | PASS — 6.905 mm VIN and GND paths |
| PCB/project SHA-256 lock | PASS — byte-identical |

The one DRC warning is the existing `U_BUCK1` footprint-type mismatch: KiCad's
heuristic sees plated thermal holes in an SMD package. It remains a release
blocker requiring assembly/thermal construction qualification; no warning was
suppressed or severity weakened.

## Explicit non-claims

- No electrical component, value, footprint, pin net, PCB object, project rule
  or firmware file was changed.
- No SSR driver, restart latch, contact supply or independent safety interlock
  was added.
- The drawing cleanup does not qualify current capacity, thermal behavior,
  timing, EMC, analogue range, laser reset-off behavior or fault safety.
- No Gerbers or production assembly files were generated.

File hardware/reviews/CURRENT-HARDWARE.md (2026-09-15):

# Current hardware checkpoint

## Schematic layout checkpoint (2026-09-15)

The canonical V2.0.10 schematic now uses five aligned functional rows with
left-to-right signal flow, top-to-bottom supply/return presentation, normalized
Reference/Value fields and short exact-name labelled connections. The drawing
contains the same 122 components and 110 nets as the pre-layout baseline; the
PCB and KiCad project are byte-identical. See the
[layout-aesthetics review](2026-09-15-v2-schematic-layout-aesthetics.md).

This is a drawing-only revision after V2.0.10, not a new electrical release.
ERC is zero; PCB DRC still contains only the documented `U_BUCK1`
footprint-type warning. The SSR-only restart-interlock design remains
unimplemented. The hardware remains an engineering draft, not approved for
fabrication or laser operation.

SSR-only architecture update (2026-09-15): the user confirmed the DC
laser-driver branch, rejected an additional relay/contactor and approved
elaboration of hardware stop gating plus restart interlock. The
[written design](../../docs/superpowers/specs/2026-09-15-ssr-only-design.md)
awaits review before implementation planning. It reuses GPIO47; GPIO40 stays
with the encoder. This is documentation only: the existing V2.0.10 circuit
does not yet implement that design. No fault-tolerant laser-safety or
production approval is implied by the user's SSR-only choice.

Electrical/PCB revision: **hw-v2.0.10-draft** (2026-09-14).
Prior schematic presentation checkpoint: readability update after export
commit `995eb85`; see the
[previous drawing-only review](2026-09-14-v2-schematic-readability.md).
The existing hardware tag is unchanged; Git records this presentation update.

**FULLY CONNECTED ROUTING DRAFT — NOT FOR FABRICATION OR LASER OPERATION.**

User scope decision (2026-09-14): thermal, load and timing work is excluded
from further activity unless requested again. Existing evidence and warnings
remain recorded; these subjects are **unverified, not passed**. Continue
mechanical, BOM/assembly, manufacturing-data and remaining safety/interface
work. The exclusion does not imply a thermal/current/timing guarantee or
fabrication/laser-operation approval.

## Latest user inputs and SSR status

Manual assembly by the user and ESP32 2.54 mm pitch are confirmed.
The carrier still uses two 1x22 female socket strips; 22.86 mm row spacing
and body alignment remain provisional. U1 Assembly/footprint descriptions
now distinguish the confirmed and unconfirmed dimensions; geometry is exact.

SSR preselection: Omron G3NA-D210B-UTU DC5-24 for the proposed DC driver-feed
branch, **not a drop-in or purchase approval**. The present NE555/330-ohm
drive does not guarantee its input requirement. Two-wire E-stop contact type,
independent interruption and rearm remain unresolved. See
[manufacturer evidence and constraints](2026-09-14-manual-assembly-ssr.md).
PDF refreshed; PCB images unchanged because visible geometry is unchanged.

## Artifacts

Paths are relative to `hardware/schematics/`.

| Artifact | State | SHA-256 |
|---|---|---|
| `Laser Controllerv2_only_for_pcb_test.kicad_sch` | V2.0.10 drawing-only functional-row layout; 122 components, 110 nets | `d764afbc6f2769a81caffe049524bf031ad04c2a1837089bfe3f07989b93a58d` |
| `Laser Controllerv2_only_for_pcb_test.kicad_pcb` | Routed v2 engineering draft with five ground zones | `b8111d778abc5b57ec3adb1bbc94060598fb87cc0d16e584e53e28c0bce4f47a` |
| `Laser Controller.kicad_pcb` | Unchanged historical board; not the v2 layout | `9703ba1bf5343e8a77ab9dbb0781785384c4f238bedc52c1341898d9e9bbf6b2` |

## PDF and PCB views

PCB views retain V2.0.10 source commit `f58ff538b2cda6d26dd76c6a4b9417fa833b695b`.
The schematic PDF is refreshed directly from the current canonical schematic.
All exports are stored directly in `hardware/`:

- [Schematic PDF](../GalvOS_V2.0.10_Schematic.pdf)
- [PCB top](../GalvOS_V2.0.10_PCB_Top.png)
- [PCB bottom](../GalvOS_V2.0.10_PCB_Bottom.png)
- [PCB perspective](../GalvOS_V2.0.10_PCB_Perspective.png)

The canonical schematic now uses a 620 x 440 mm page and separate draft
title warnings; no temporary export-only formatting is needed. Six IC
reference/value pairs and 22 nearby labels have been repositioned/oriented
for readability, with all electrical content preserved. Other legacy text
overlaps remain; this is not a complete drawing-readability sign-off.
The native KiCad 10.0.6 PNGs are unchanged at 2384 x 1568 pixels. Some parts
have no visible 3D model (including the ESP32/socket assembly and some ICs),
so these are CAD views, not proof of complete assembly or mechanical fit.
All draft restrictions remain applicable.

## Implemented

- Drawing-only update after V2.0.10: moved selected IC fields outside bodies,
  hid two footprint display fields, oriented 22 labels outward, and fixed
  canonical page/title clipping. All 122 component definitions, 110 named
  nets/classes, pin mappings, wires and electrical anchors are unchanged;
  PCB/project hashes match V2.0.10. PDF regenerated from the canonical source.
  See [readability proof and remaining work](2026-09-14-v2-schematic-readability.md).

- V2.0.10 resolves the two trigger-diode package identities using standard 1N4148W symbols and explicit Diodes Incorporated 1N4148W-7-F manufacturer/MPN/assembly fields. SOD-123 geometry, all 122 placements, all 400 pad records, all 1115 copper objects and all 110 electrical nets are unchanged. Only two diode values/identities and metadata change. The negative-only clamps still do not qualify timer-input protection or laser safety. See [package/polarity review](2026-09-14-v2-diode-package.md).

- V2.0.9 moves the four existing 22 ohm DAC source resistors closer to the translator. Source links drop from 6.783–16.095 mm to 2.796–6.352 mm, all on F.Cu without vias. Only four placements and local source/DAC-side routing change; 118 placements and 1084 retained copper objects are exact. All 122 values/footprints and 110 nets remain unchanged. The native source-layout guard and six negative fixtures pass; 40 MHz timing remains unqualified. See [source-layout evidence](2026-09-14-v2-dac-source-layout.md).

- V2.0.8 moves R26 toward the MCU/DAC boundary, adds two local front-layer return zones and three AGND stitching vias, and preserves all signal routing. Geometric opposite-layer ground overlap on the four DAC input nets improves from 1.8–31.9% to 74.8–90.7%; this does not qualify impedance, timing or EMC.
- User reports a 28 x 57 mm ESP32 body with 22 pins per side. Updated U1's placed/library body and courtyard while preserving all 44 pads. Two bypass capacitors move/rotate clear of the wider module while retaining their VCC pad positions. Their ground routing and two nearby supply-feed segments are adapted. Pin-grid centering, 2.54 mm pitch, 22.86 mm row spacing and antenna/USB clearance remain provisional.
- In V2.0.8, against V2.0.7: all 122 values/footprint assignments and all 110 net memberships are unchanged; 119 placements and 1104 retained copper objects are preserved. Ten obsolete copper objects are replaced by fifteen scoped objects; project rules and the legacy PCB are unchanged. See the [V2.0.8 return/mechanics review](2026-09-14-v2-return-layout.md).

- V2.0.7 relocates the existing C_IN2 10 uF capacitor beside C_INHF1. Its VIN and ground paths to U_BUCK1 are each 6.905 mm of direct F.Cu routing, without vias in those local connections. Six obsolete capacitor stubs/vias are removed and two 0.8 mm local traces added. All values, footprint types and electrical memberships are unchanged; 121 placements are retained.
- The exact-object audit found two coincident +3V3 trace pairs carrying duplicate IDs since V2.0.5's UUID restoration. V2.0.7 removes one identical copy from each pair, without changing the occupied +3V3 copper geometry. All 1112 retained unique baseline copper objects match their original geometry/width/IDs. The new input-layout guard also rejects duplicate copper IDs.

- V2.0.6 corrects C_INHF1 from 100 nF to TI's 220 nF / 50 V X7R requirement, specifies ceramic ratings for C_BOOT1/C_VCC1, and preserves every electrical net. R_FB1/R_FB2 move close to the buck FB pin; total FB trace length drops from 23.655 to 6.550 mm and its two vias are removed. The ground spur is replaced by a local return to the exposed-pad ground; BOOT/VCC traces widen from 0.25 to 0.40 mm. No load/current/thermal or loop-stability rating is established by this change.
- Against V2.0.5: 120 placements, all pad geometry and all pad nets are preserved. Of 1128 old copper items, 1108 are unchanged, 17 obsolete feedback/ground/stub items are removed and three BOOT/VCC tracks are widened. Nine short front-layer tracks replace the removed routing. The only component value change is C_INHF1; no footprint is replaced or added.

- V2.0.5 adds U_DMXLV1 (SN74LVC1G17DBVR), R_DMXIN1 (10 kohm pull-down) and C_DMXLV1 (100 nF bypass). J_DMX1.3 now drives the 5.5 V-tolerant input; the 3V3-powered noninverting output drives GPIO4. The module supply/pinout and firmware are unchanged. A disconnected module holds RX LOW/break; this is not an independent laser-off function.
- Against v2.0.4, exactly those three components and the RO/3V3/power-ground memberships change. All 119 previous footprints/placements and pad geometry are preserved; only J_DMX1.3 changes pad net. Of 1098 baseline copper items, 1097 retain exact geometry (five renamed); one RO diagonal is trimmed by 1.8 mm on each axis. All retained item UUIDs were restored after router import. New copper is confined to the local DMX stage and its supply/ground connections.

- Preserve the approved external 12 V fan rails: J4.1–J5.2 and J6.1–J7.2, separate from each other and the buck positive rails. J2 supplies 12.6 V to the 5 V buck.
- Added U_SCANLV1 (SN74LVC1G17DBVR), R_SCANIN1 (10 kohm input pull-down) and C_SCANLV1 (100 nF local bypass). The timer's 5 V output no longer directly drives GPIO39. The buffer uses MCU +3V3 and power ground, preserving HIGH=OK. Full supply/temperature/fault qualification remains open; see the scan-status review.
- The earlier V2.0.4 change against v2.0.3 added exactly three components and changed only the status/3V3/power-ground memberships. All previous values, footprints and unrelated electrical memberships match. Firmware and shutdown/arming logic are unchanged.
- PCB: 175 x 115 mm closed outline, two copper layers, nominal 1.6 mm thickness, 122 footprints, 1011 trace segments, 104 vias and five filled ground zones (two new zones explicitly named).
- In V2.0.4, all original 116 footprint placements and pad geometries are preserved. Removed one original GPIO39 segment at the MCU end and reassigned the other six status copper items to SCAN_STATUS_5V. All 1066 retained baseline copper items were verified exactly after that rename. Unrelated autorouter normalization was restored from the baseline.
- U1 already specifies two 1x22 female socket strips; corrected the footprint's stale 21/20-pin description. Retained all 44 pads, 2.54 mm pitch and provisional 22.86 mm row spacing. V2.0.8 adds the user-reported 28 x 57 mm body envelope; actual pin-grid alignment, fit and antenna/USB clearance remain unqualified.
- Repositioned seven analog parts for local feedback/supply routing; routed analog feedback, output and bypass connections manually. All 30 pre-autoroute segments survived the routing import exactly, along with every footprint position and pad net.
- Completed remaining routing in an isolated offline candidate, corrected sub-minimum neckdowns, added an R9 escape via and verified the candidate before adopting it.
- Added B.Cu AGND and power-ground planes, plus local F.Cu buck thermal copper. U_BUCK1 exposed-pad/thermal-hole pad 9 uses solid zone connection. Isolated copper removal is enabled. These first planes do not qualify the MCU/DAC return boundary or system EMC.
- `PowerDraft` retains provisional 0.8 mm routing for both fan-positive rails, VIN_RAW, VIN_BUCK and Buck +5V. Default signal routing is 0.25 mm, minimum 0.20 mm; vias are 0.60/0.30 mm. Minima include 0.20 mm copper clearance, 0.50 mm copper-to-edge and 0.10 mm silk clearance. No current rating or copper-weight/temperature qualification is claimed.

## Verification

KiCad 10.0.6, native all-severity DRC with schematic parity and freshly refilled zones:

- ERC: **0 violations**.
- PCB: **0 unconnected items**, **0 non-routing errors**, **1 footprint-type warning**.
- Native schematic-parity section: **0 findings**. Both diode-filter warnings are resolved by explicit matching SOD-123 part identities, not exclusions.
- No reported shorts, clearance/courtyard conflicts, undersized tracks, silk collisions, isolated copper or starved thermals.
- DAC, sensor/tach, fan-power, scan-status, DMX, buck and trigger-diode interface checks pass. The diode checker also verifies only the two approved identity changes against V2.0.9; all electrical net memberships remain identical. Earlier optional baseline comparisons in individual historical reviews apply to their named revisions.
- Input-layout guard proves the two explicit same-layer connections and unique copper IDs; negative checks reject the old duplicate-ID board and a candidate with the local VIN link removed. Its 8 mm/0.60 mm limits are project-local routing guards, not manufacturer electrical ratings.
- Draft-evidence guard passes. Sixty-five unit tests include the schematic
  electrical-preservation and presentation contracts plus the existing
  report/rule, interface and SMD-placement coverage. Resolved diode warnings
  remain disallowed. Passing the draft guard is not production approval.
- Combined front/back copper and the revised module outline/placements were rendered and inspected. Native inspection confirms five filled zones assigned to the intended ground nets. The read-only DAC overlap diagnostic records geometric improvement, not electrical qualification.
- Current local verification includes export, seven interface checks, 65 unit
  tests, both native layout guards, ERC and native DRC/parity. Results are
  recorded in the current layout-aesthetics review.

Remaining known warning:

1. `U_BUCK1`: KiCad's type heuristic expects through-hole because the SMD footprint contains plated thermal holes. Qualify the exposed-pad, solder/paste, thermal-hole and assembly construction.
The former D_TRIGCL_SCAN1/D_TRIGCL_WD1 package warnings were resolved in V2.0.10. Reappearance is a failed draft gate; trigger-circuit electrical and safety qualification remains open.

Correction to the v2.0.2 report: its committed project actually retained **0.00 mm** minimum silk clearance, despite the documented 0.10 mm intent. Native save/export operations reset this setting. V2.0.3 explicitly stores and verifies 0.10 mm; the new guard rejects the old/reset value and skipped checks. No findings were excluded.

## Assembly export coverage

The native SMD position export contains 97 parts. Do not add
`--exclude-fp-th`: it removes U_BUCK1 because this SMD package contains
plated holes. The new
`hardware/tests/check_smd_placement_coverage.py` compares the actual PCB's
populated SMD inventory with native CSV references, values, packages and
sides. It passes the 97-row export and rejects the real 96-row negative
export for the missing buck; it does not qualify coordinates or rotations.

The buck's 2.60 x 3.10 mm mask/paste opening matches TI's DDA0008J example
for a 0.125 mm stencil; do not change it merely to suppress a type warning.
The actual assembly process and via treatment need confirmation.
See [assembly evidence and reproduction](2026-09-14-v2-assembly-export.md).
The user confirmed manual assembly; equipment/process for the concealed
buck-pad joint still needs qualification. No production assembly files were issued.

## Reproduce

```sh
kicad-cli sch export netlist --format kicadxml -o /tmp/galvos-current.xml \
  'hardware/schematics/Laser Controllerv2_only_for_pcb_test.kicad_sch'
PYTHONDONTWRITEBYTECODE=1 python hardware/tests/check_fan_power.py /tmp/galvos-current.xml
PYTHONDONTWRITEBYTECODE=1 python hardware/tests/check_sensor_fan_interfaces.py /tmp/galvos-current.xml
PYTHONDONTWRITEBYTECODE=1 python hardware/tests/check_dac_interface.py /tmp/galvos-current.xml
PYTHONDONTWRITEBYTECODE=1 python hardware/tests/check_scan_status.py /tmp/galvos-current.xml
PYTHONDONTWRITEBYTECODE=1 python hardware/tests/check_dmx_interface.py /tmp/galvos-current.xml
PYTHONDONTWRITEBYTECODE=1 python hardware/tests/check_buck_interface.py /tmp/galvos-current.xml
PYTHONDONTWRITEBYTECODE=1 python hardware/tests/check_trigger_diodes.py /tmp/galvos-current.xml
PYTHONDONTWRITEBYTECODE=1 python -m unittest discover -s hardware/tests -p 'test_*.py'
kicad-cli sch erc --format json --severity-all --exit-code-violations \
  -o /tmp/galvos-current-erc.json \
  'hardware/schematics/Laser Controllerv2_only_for_pcb_test.kicad_sch'
kicad-cli pcb drc --refill-zones --schematic-parity --all-track-errors \
  --format json --severity-all -o /tmp/galvos-current-drc.json \
  'hardware/schematics/Laser Controllerv2_only_for_pcb_test.kicad_pcb'
PYTHONDONTWRITEBYTECODE=1 python hardware/tests/check_pcb_draft.py \
  /tmp/galvos-current-drc.json \
  'hardware/schematics/Laser Controllerv2_only_for_pcb_test.kicad_pro'
```

Also run the native layout guards with KiCad's Python bindings:

```sh
/usr/bin/python -B hardware/tests/check_dac_source_layout.py \
  'hardware/schematics/Laser Controllerv2_only_for_pcb_test.kicad_pcb'
/usr/bin/python -B hardware/tests/check_buck_input_layout.py \
  'hardware/schematics/Laser Controllerv2_only_for_pcb_test.kicad_pcb'
```

PCB DRC deliberately collects the remaining warnings. Its process exit code alone is not proof. Read the report and run the draft guard; do not disable package warnings to obtain an apparent clean result.

## Release remains blocked by engineering work

Routing connectivity is complete, not production qualification. Continue actual ESP32/header fit, antenna/USB and enclosure/connector mechanics, complete BOM/assembly review, manufacturing-data correctness and independent review. Remaining safety/interface gates include independent Class 4 shutdown/rearm, E-stop/override behavior, RGB reset-off drive, scan-fail limitations, external interface protection and physical safety qualification. Thermal, load/current-capacity and timing findings remain unverified but are excluded from further work by explicit user request; do not treat that exclusion as evidence of compliance. V1 perfboard operation does not qualify v2 fault safety. No Gerbers have been generated.

Existing circuit gates remain: independent Class 4 shutdown/rearm, E-stop/override behavior, RGB reset-off drive, DMX module/receiver/cable qualification and fan PWM contracts, analog output range, scan-fail limitations and full buffer/timer qualification, buck ratings and input protection. Physical testing is required. V1 perfboard operation does not qualify v2 or fault safety. No Gerbers were generated.

See [V2.0.8 return/mechanics change](2026-09-14-v2-return-layout.md), [shutdown-boundary evidence](2026-09-14-shutdown-boundary.md), [local input-capacitor change](2026-09-14-v2-buck-input.md), [buck feedback/bypass change](2026-09-14-v2-buck-layout.md), [DMX input change](2026-09-14-v2-dmx-input.md), [scan-status change](2026-09-14-v2-scan-status.md), [v2.0.3 routing evidence](2026-09-14-v2-routing.md), [remaining plan](2026-09-14-v2-pcb-plan.md) and `codex-todos.md`.

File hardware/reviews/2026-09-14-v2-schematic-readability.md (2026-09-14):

# V2.0.10 schematic readability update — 2026-09-14

## Scope and evidence

Baseline: export commit `995eb85872eb54f38ede0726ccb4051b6725de39`;
electrical/PCB source tag `hw-v2.0.10-draft` remains unchanged.

The exported drawing exposed visible footprint strings, reference/value
fields inside IC bodies, inward-pointing local labels and an undersized
canonical A2 page. Native before/after PDF crops confirmed these causes.

This update changes presentation only:

- Canonical page: 620 x 440 mm, short V2.0.10 DRAFT revision, separate
  NOT FOR FABRICATION and NOT FOR LASER OPERATION warnings.
- Reference/value fields moved outside U1, U2, U12, U_BUCK1, U_WD1 and
  U_SCAN1. U1 fields also avoid the existing wires above its body.
- U2/U12 Footprint fields hidden, with their assigned values preserved.
- 22 labels at buck/watchdog/scan IC pins oriented outward; label text,
  UUIDs and XY electrical anchors remain unchanged.
- PDF refreshed directly from the canonical schematic. No export-only
  source transformation remains. PCB images stay unchanged/current.

## Preservation proof

An independent root-block comparison allows only page/title changes,
selected field presentation and label angle/justification. It found
797 exact unchanged blocks, six changed symbol display blocks, 22 changed
label display blocks and two page/title blocks. No symbols, wires, junctions,
pins, images or electrical anchors were added, removed or relocated.

Fresh KiCad XML exports before and after adoption have **byte-identical
components, libparts, libraries and nets subtrees**, including every
component property, pin definition and net class. No normalization was used
for the final canonical comparison: 122 components, 110 named nets.

The isolated candidate initially omitted the local libraries/project and
produced six missing-library ERC warnings and default net classes.
The unchanged project configuration, tables and libraries were copied into
the candidate directory before repeating validation; warnings disappeared
and the full net classes matched. These first incomplete-environment results
are not counted as passes.

## Verification

KiCad 10.0.6; canonical final files:

- ERC, all severities: zero findings.
- Native DRC with refill, all-track errors and schematic parity: zero
  errors, zero unconnected items, zero parity findings.
- One existing U_BUCK1 footprint-type warning remains; draft guard passes.
- Seven interface checkers pass: fan power, sensors/tach, DAC, scan status,
  DMX, buck and trigger-diode identity/polarity.
- All 41 hardware unit tests pass.
- Native PDF full-page and changed-region crops visually inspected.
  Page/title fit is corrected. Existing overlaps elsewhere remain.

Reproduction commands for native export, ERC, DRC, interfaces and unit tests
are in [CURRENT-HARDWARE.md](CURRENT-HARDWARE.md#reproduce).
For electrical preservation, export baseline and current schematics with
their matching project filenames/configuration and compare the XML
`components`, `libparts`, `libraries` and `nets` subtrees; only the
`design` metadata may differ. Git diff establishes the scoped drawing edits.

| Artifact | SHA-256 |
|---|---|
| Canonical SCH | `adb9bf0af905d7a063de0bc2b287c3bc65b554794207a8d884ebd85c7f033f29` |
| PCB, unchanged | `267c312d4451f386fe3bcb2e500c779456d1787064c24c7be033837a4de578ee` |
| PRO, unchanged | `dc77f4155067018d81c509e667ad67642031a5cf69abe7181144c19c11bd3b1b` |
| Refreshed PDF | `55ec864fb20cc925e97bd9cdc02804c4251efaf5aa8d7ffaef8a58df70f5041c` |

## Remaining gates

This is a scoped readability improvement, not a complete drawing sign-off.
Legacy passive-component labels and MCU pin labels still overlap. Actual
ESP32 row spacing/grid alignment, USB/antenna/enclosure fit, BOM/assembly
qualification, manufacturing-data review and independent shutdown/rearm
remain open. No firmware or KiBot changes were made.

Thermal, load and timing remain excluded from further work at the user's
request and unverified, not passed. No Gerbers, fabrication release or
laser-operation approval.

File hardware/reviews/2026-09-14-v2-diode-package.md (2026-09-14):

# Trigger-diode package identity — V2.0.10 draft

Date: 2026-09-14. Baseline: `d5296757928db13225d147827076c8460646e2ab`
(`hw-v2.0.9-draft`). **Not for fabrication or laser operation.**

## Cause and selected part

D_TRIGCL_SCAN1 and D_TRIGCL_WD1 used the axial `Diode:1N4148` symbol,
DO-35 description/datasheet and DO-35 footprint filter, but the PCB already
used `Diode_SMD:D_SOD-123`. That is an ambiguous purchasing/assembly
specification, not a warning to waive.

Reused the installed standard `Diode:1N4148W` symbol. Its inherited diode
graphics, pin positions, passive electrical types and numbering are the
same as the previous symbol. The two placed instances and PCB footprints
now explicitly select:

| Field | Both diode positions |
|---|---|
| Value | 1N4148W |
| Manufacturer | Diodes Incorporated |
| MPN | 1N4148W-7-F |
| Package / footprint | SOD123 / Diode_SMD:D_SOD-123 |
| Cathode | Pad 1, cathode band; respective timer TRIG pin 2 |
| Anode | Pad 2, MCU/timer power ground |

Manufacturer and orderable MPN are canonical schematic/PCB fields, not an
inferred substitution based only on the generic value. The selected part's
datasheet overrides the generic symbol catalog's default datasheet.

Primary evidence: [Diodes Incorporated DS30086, Rev. 31-2, September 2024](https://www.diodes.com/assets/Datasheets/ds30086.pdf).
Downloaded and inspected the five-page manufacturer PDF; SHA-256:
`39c16a6888bdab22418e93e17182174aad763a66957a4632e70c944194e3fc08`.
It explicitly lists 1N4148W-7-F, SOD123, 3000-piece tape/reel and cathode-band
polarity. Live stock and assembler sourcing have not been verified.
The Nexperia URL returned a challenge page and the catalog's Vishay URL
returned 404; neither is treated as verified manufacturer evidence.

## Package / polarity check

Both existing footprints are unrotated. Pad 1 lies left of the body center
and the existing silk cathode bracket is on that same side. The package's
cathode band must face this bracket; no diode or net was reversed.

| Geometry | Selected package | Existing PCB |
|---|---|---|
| Body | 2.55–2.85 x 1.40–1.70 mm; height 1.00–1.35 mm | SOD-123 footprint retained |
| Overall lead span | 3.55–3.85 mm | Pads centered at ±1.65 mm |
| Lead contact length / width | 0.25–0.40 / 0.52–0.62 mm | Each pad 0.90 x 1.20 mm |
| Suggested pad layout | 0.90 x 0.95 mm; overall pad span 4.05 mm | 0.90 x 1.20 mm; overall pad span 4.20 mm |

The installed KiCad pad layout is not identical to the suggested pattern.
With ideal centering and the stated package tolerances, each lead contact
lies within the rectangular pad envelope: minimum longitudinal toe/heel
allowance is 0.175 mm and minimum transverse side allowance is 0.29 mm.
These are geometric calculations, not solder-joint, placement-tolerance,
paste-process or assembly-yield qualification. No footprint, pad, courtyard,
position, rotation, mask/paste geometry or copper was changed.

## Electrical limits and remaining trigger risk

The selected manufacturer's limits at the specified conditions include
100 V DC/repetitive reverse voltage, 300 mA continuous forward current,
2 pF maximum capacitance at 0 V / 1 MHz, and 4 ns maximum recovery at the
documented 10 mA test conditions. VF is at most 0.715 V at 1 mA and 0.855 V
at 10 mA, at 25 C. These are device specifications, not measured circuit
performance or a board current rating.

In particular, the 400 mW / 315 C/W thermal figures use the datasheet's
large 2 x 2 inch anode/cathode copper pads and 3 oz double-sided board.
They do not describe these SOD-123 pads. Actual peak clamp current,
temperature, supply sequencing and trigger timing remain unqualified.

Both diodes are still **negative-only clamps**. They cannot limit positive
trigger excursions to the timer's supply. The [analog review](2026-09-14-analog-path.md)
already identifies scan loading, axis cancellation, insufficient trigger
sensitivity and modeled excursions above VCC; TI NE555 SLFS022K lists VCC
as the maximum trigger-input voltage. The watchdog's AC-coupled input also
needs complete waveform/current qualification. Correct package identity
does not repair or validate these circuits and does not establish an
independent laser shutdown function.

## Preservation and verification

- Same 122 components and footprint assignments; only the two generic diode
  values/identities change. All other values and all 110 net memberships
  match V2.0.9 exactly.
- All 122 placements/rotations, 400 placed pad records, 1115 copper objects
  and five zone blocks remain exact. All wires/labels and the diode symbol's
  pin geometry are unchanged. Board still has 1011 segments and 104 vias.
- Added hidden Manufacturer, MPN and Assembly fields. Updated the draft
  revision to V2.0.10; firmware, project rules, legacy PCB and KiBot unchanged.
- Native KiCad 10.0.6 ERC: zero. All-severity DRC, zone refill, all-track
  checking and schematic parity: zero errors, zero unconnected items,
  **zero parity findings**. Only U_BUCK1's existing thermal-hole footprint
  type warning remains. No native rule was relaxed or excluded.
- Removed the two resolved diode warnings from the draft checker's allowed
  warning set. A regression test rejects either warning if it returns.
- Seven interface checkers, 41 unit tests and the native DAC-source and
  buck-input/unique-ID guards pass. The new diode checker rejects V2.0.9,
  verifies the two allowed identity changes against that baseline, and
  checks actual manufacturer/MPN/datasheet, symbol identity and K/A polarity.
  New unit tests reject axial/wrong-package selection, reversed pads, wrong
  ground, wrong BOM fields, old symbol identity and swapped symbol pins.
- A relocated copy of the staged hardware repeats export, all seven interface
  checks, the exact V2.0.9 delta comparison, 41 unit tests, ERC, all-track
  DRC/parity and both native layout guards. All recorded artifact hashes
  match; user-owned untracked files are excluded.

## Reproduce

Run the current checkpoint's complete native ERC/DRC and interface test set,
including:

```sh
/usr/bin/python -B hardware/tests/check_trigger_diodes.py /tmp/galvos-current.xml
/usr/bin/python -B -m unittest discover -s hardware/tests -p 'test_*.py'
```

An optional second XML argument to the diode checker must be a V2.0.9
netlist; the checker permits only these two diode identity changes.

[Recorded hashes and checks](2026-09-14-diode-package-checks.json);
[current hardware checkpoint](CURRENT-HARDWARE.md).

Full production gates remain: independent Class 4 shutdown/rearm and RGB
reset-off, trigger/analog redesign decisions, DAC timing, actual loads and
buck thermal/stability/protection, ESP32 pin-grid/antenna/USB/enclosure fit,
complete BOM/assembly review and physical qualification. No Gerbers made.

After this verification, the user explicitly excluded further thermal, load
and timing work. Their existing findings remain unverified and documented;
they are not queued for further activity or treated as passed. This does
not change the diode package/polarity evidence or the remaining mechanical,
assembly and laser-safety work, and does not confer a release approval.

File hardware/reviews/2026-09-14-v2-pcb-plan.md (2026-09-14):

# V2 PCB implementation plan

Current user scope decision (2026-09-14): do not continue thermal, load or
timing analysis/qualification. Historical findings below remain evidence,
not passes; those topics are no longer queued for work. Continue mechanical
fit, BOM/assembly, manufacturing-data and remaining safety/interface tasks.
Do not hide DRC warnings or infer fabrication/laser-operation approval.

Latest: V2.0.10 specifies matching SOD-123 trigger-diode symbols and orderable
manufacturer parts, with unchanged pads/copper/nets. The two package warnings
are resolved; complete timer-input and laser-safety qualification is not.
See [package review](2026-09-14-v2-diode-package.md).

V2.0.9 shortens all four DAC source links, removes their six source vias,
and preserves unrelated circuitry. See [source-layout review](2026-09-14-v2-dac-source-layout.md).
Timing, physical qualification and the existing production-release gates remain open.

Goal: a separate schematic-matched v2 PCB using approved external 12 V fan supplies and 12.6 V buck input. Preserve the legacy PCB and user-owned untracked `agents.md`. Use explicit staging and intermediate versioned pushes; draft checkpoints are not production releases.

## Approved architecture

J2 supplies the buck at 12.6 V; the buck supplies 5 V electronics. J4/J6 supply J5/J7 respectively at external 12 V. Both positive fan rails are separate from each other and the buck positive rails, with common power ground. New two-layer board: provisional 175 x 115 mm outline. Preserve inverted RGB, independent DAC/SD SPI buses and safety functions. No unrelated circuit/firmware changes or Gerbers.

## V2.0.2 implementation checkpoint

- [x] Export original v2.0.1 netlist; demonstrate fan-power checker fails before the change.
- [x] Split exactly four fan-positive pin memberships into two isolated rails; update J2/J4/J6 values and annotations.
- [x] Pass baseline preservation, DAC and sensor/tach tests, fresh ERC and five negative fan tests.
- [x] Create separate board from all 116 components; repair importer pad-net names, component fields and schematic links. Do not copy historical copper.
- [x] Establish two copper layers, 1.6 mm nominal thickness and closed 175 x 115 mm outline; place by functional block.
- [x] Correct courtyard/silkscreen collisions; improve buck bypass/bootstrap placement and references; add draft/input/polarity markings.
- [x] Set provisional geometry rules without claiming current capacity. Enable additional footprint/missing-courtyard/via checks.
- [x] Add initial fan/buck routing: 15 segments; inspect rendering and fresh native DRC/parity.
- [x] Record hashes/findings in `CURRENT-HARDWARE.md`: 251 unconnected items, one footprint-type warning, two footprint-filter warnings. No other native findings.
- [x] Commit/tag/push `hw-v2.0.2-draft`, then verify remote branch/tag. Hardware commit `19553b47054e940e130fff27a91c6b8e198509f6`; remote main and peeled tag matched after the atomic push.

## Further work — not completed by this checkpoint

- [x] Establish a fully connected draft and first separated ground planes in v2.0.3: 964 segments, 103 vias, three filled/named zones, zero unconnected items. See `2026-09-14-v2-routing.md`.
- [ ] Qualify/refine ground distribution, MCU/DAC return boundary/R26 and critical buck loop, feedback and thermal layout; connectivity alone is insufficient.
- [ ] Qualify actual currents, copper weight, MPNs and voltage/temperature derating; update trace/via/pour sizing.
- [ ] Resolve diode package/filter and buck thermal-hole assembly warnings without concealing findings.
- [ ] Qualify enclosure/mounting/connectors and MCU antenna/USB access; establish actual keepouts.
- [ ] Obtain independent electrical/layout/BOM review. No independent agent review was performed for this checkpoint.
- [ ] Resolve electrical safety/level/interface blockers, pass complete ERC/DRC/parity and perform physical qualification before release.

Later routing checkpoints need subsequent draft versions. The full production objective remains incomplete.

## V2.0.4 scan-status input protection

- [x] Confirm two 1x22 female socket strips are already specified; correct the stale footprint description without changing U1 pads or routes.
- [x] Insert a 5.5 V-tolerant, 3V3-powered noninverting buffer between U_SCAN1.3 and GPIO39, with input pull-down and local bypass.
- [x] Verify the exact three-component electrical change against v2.0.3; pass all four interface checks and seventeen unit tests.
- [x] Route the new stage; retain all 116 original footprints/placements and all 1066 retained baseline copper items after the status-net rename. Refill and retain three ground zones.
- [x] Fresh ERC: zero findings. Native DRC/parity: zero unconnected items, only the same three documented package warnings. Draft guard passes with unchanged project rules.
- [ ] Qualify timer/buffer signaling over actual supply and temperature corners, power sequencing and fault cases. The input-protection change does not qualify laser safety.

## V2.0.3 publication

The subsequent V2.0.5 checkpoint is detailed below; this section records the
historical V2.0.3 publication.

- [x] Preserve the v2.0.2 electrical netlist and legacy PCB; update draft revision text.
- [x] Add draft-evidence checks and nine negative/positive unit tests; correct the actual stored silk minimum to 0.10 mm.
- [x] Inspect routed front/back copper and filled planes; repeat native DRC/ERC and interface checks.
- [x] Commit/tag/push `hw-v2.0.3-draft` and verify remote references. Hardware commit `dcd5d718ce7d57131ba7a3da06afa7a667071112`; remote main and peeled tag matched after the atomic push.

## V2.0.5 DMX input protection

- [x] Add a 5.5 V-tolerant, 3V3-powered noninverting buffer, pull-down and bypass
  between module RO and GPIO4; retain connector pinout, supply and firmware.
- [x] Verify exactly three new components against V2.0.4; pass all five interface
  checks and 28 unit tests, including eleven DMX connectivity cases.
- [x] Finish routing with no unconnected items; retain 119 original placements,
  all pad geometry, and baseline copper except the documented RO split/trim.
- [x] Pass ERC and native DRC/parity draft guard with unchanged project rules;
  retain only the three known package warnings and all three filled ground zones.
- [ ] Qualify actual module RO levels/load/power sequencing and cable/ESD/bus
  circuitry; review receive timeout and short-frame behavior separately.
- [ ] Resolve all broader release gates; V2.0.5 is still not for fabrication.

## V2.0.6 buck feedback and bypass

- [x] Correct the local HF bypass to TI's 220 nF/50 V/X7R requirement and specify
  BOOT/VCC ceramic ratings without changing net membership or footprint types.
- [x] Move the existing feedback divider near FB; reduce total FB trace length
  from 23.655 to 6.550 mm, remove FB vias, provide a short local ground return,
  and widen existing BOOT/VCC traces to 0.40 mm.
- [x] Prove 120 unchanged placements/all pad nets and the exact copper delta;
  pass six interface checkers, 33 tests, zero-finding ERC and draft DRC/parity.
- [ ] Qualify actual loads, L/C parts/derating, input hot loop, current/thermal
  capacity and loop stability. This checkpoint does not close those gates.

## V2.0.7 local input capacitor

- [x] Move existing C_IN2 beside the local HF bypass; provide direct 6.905 mm
  F.Cu VIN/ground connections, preserving values and electrical memberships.
- [x] Preserve 121 other placements and exact scoped copper; remove obsolete
  capacitor stubs/vias and two pre-existing exact +3V3 duplicate objects.
- [x] Add a native input-layout/ID guard with negative checks; pass the six
  interface checkers, 33 unit tests, ERC and native DRC/parity draft guard.
- [ ] Qualify effective input capacitance, actual source/load currents,
  transient behavior and thermal/EMC performance. No supply rating assigned.

## V2.0.8 return copper and reported module envelope

- [x] Relocate R26 toward the MCU/DAC boundary, add two front-layer return
  zones and ground stitching, preserving all signal routing and net membership.
- [x] Apply the user-reported 28 x 57 mm ESP32 envelope to placed/library
  graphics, preserve 44 socket pads, and clear the two bypass-capacitor
  collisions exposed by the larger body/courtyard.
- [x] Pass fresh ERC, native DRC/refill/parity, six interface checkers,
  33 unit tests, input-layout/ID guard and exact copper/placement preservation.
- [x] Record sampled opposite-layer ground overlap improvement, with explicit
  limits: no impedance, return-current distribution, SPI timing or EMC claim.
- [ ] Confirm actual header pitch/row spacing and body-to-pin-grid alignment;
  qualify antenna/USB access, installed height and enclosure fit.
- [ ] Qualify remaining ground discontinuities/return paths, SPI timing,
  actual loads and thermal/EMC behavior, plus all system safety release gates.

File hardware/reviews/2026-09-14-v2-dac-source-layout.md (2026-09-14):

# DAC source-termination layout — V2.0.9 draft

Date: 2026-09-14. Baseline: `f29ffd0494d83855157dfe3d3dfa84a241f2b0d5`
(`hw-v2.0.8-draft`). **Not for fabrication or laser operation.**

## Evidence and change

The [DAC interface review](2026-09-14-dac-interface.md) already requires the
22 ohm resistors immediately beside U_DACLV1's outputs. Native measurement
found long un-terminated source links, including two vias on the clock.
Moved only R_DACCLR1, R_DACSYNC1, R_DACDIN1 and R_DACSCLK1, retained their
1206 footprints, values, orientation and electrical nets, and rerouted their
eight source/DAC-side nets locally. All four source links now use F.Cu only.

| Signal | Source length before (mm) | After (mm) | Source vias before → after | New resistor center (mm) |
|---|---:|---:|---|---|
| SCLK | 11.629 | 2.962 | 2 → 0 | 73.2, 33.8 |
| DIN | 7.238 | 2.796 | 0 → 0 | 73.2, 31.2 |
| SYNC | 6.783 | 4.563 | 2 → 0 | 73.2, 28.6 |
| CLR | 16.095 | 6.352 | 2 → 0 | 73.2, 26.0 |

These are the complete trace lengths on the buffer-to-resistor nets, not
buffer-to-DAC delay or total signal length. The DAC-side routes change and
one DAC-side CLR via is added. The four existing 1206 packages constrain
fanout spacing. This improves source-resistor locality; it does not prove
termination value, rise time, ringing, impedance, timing or EMC compliance.

The isolated offline Freerouting 2.4.1 run supplied only the four DAC-side
routes. No complete router import was adopted: it normalized unrelated
copper and attempted unrelated connections. Only the selected local paths
were recreated on the baseline; a 0.1874 mm neckdown was raised to the
existing 0.20 mm minimum. Five obsolete DAC-side tails were removed.
References retain 0.8 mm text and 0.12 mm stroke, relocated clear of pads/silk.

## Preservation and checks

- 122 component values/footprint assignments and all 110 net memberships
  are identical to V2.0.8. Schematic change is draft-revision text only.
- 118 placements unchanged. All pad geometry, relative positions, nets and
  UUIDs unchanged; all footprint rotations unchanged.
- 1084 retained copper objects preserve exact UUIDs, nets, coordinates,
  layers, widths and drills. Removed 35 objects (30 old source objects and
  five obsolete DAC-side tails), added 31 local objects.
- Final board: 1011 segments, 104 vias, 122 footprints, five filled ground
  zones. Outline/layer stack and project-rule file unchanged.
- Native KiCad 10.0.6 ERC: zero findings. Refilled, all-track DRC with
  schematic parity: zero errors and zero unconnected items. Only the
  previous buck footprint-type warning and two diode-filter warnings remain.
- Six interface checkers, 33 existing unit tests, draft-evidence guard and
  buck-input/unique-copper-ID guard pass.
- New native `check_dac_source_layout.py` verifies each 22 ohm source
  link as one connected, branch-free F.Cu chain, without vias, at least
  0.20 mm wide. Its 3.2/3.2/4.8/6.6 mm bounds are project-local regression
  limits, not manufacturer ratings.
- V2.0.8 fails the new source guard. Six independent text-mutated PCB
  fixtures are rejected: missing segment, added via, wrong layer, branch,
  excessive length and wrong resistor value. An initial native in-memory
  mutation harness failed during object teardown/reloading; it is not
  counted as successful test evidence.
- The four MCU-side geometric ground-overlap measurements remain identical
  to V2.0.8 (75.602%, 74.781%, 78.571%, 90.677%). This remains geometric
  evidence only. Native front-copper/silk and combined-layer views inspected.
- A relocated staged hardware copy repeats netlist export, all six interface
  checks, 33 unit tests, ERC, native DRC/parity and both native layout guards.
  The artifact hashes, preservation proof and overlap measurements match.
  User-owned untracked files are not included.

## Reproduce

Use the current checkpoint's export, six interface checks, unit tests,
ERC, all-track DRC/parity and draft-evidence commands, then:

```sh
/usr/bin/python -B hardware/tests/check_dac_source_layout.py \
  'hardware/schematics/Laser Controllerv2_only_for_pcb_test.kicad_pcb'
/usr/bin/python -B hardware/tests/check_buck_input_layout.py \
  'hardware/schematics/Laser Controllerv2_only_for_pcb_test.kicad_pcb'
/usr/bin/python -B hardware/tests/measure_dac_return_layout.py \
  'hardware/schematics/Laser Controllerv2_only_for_pcb_test.kicad_pcb'
```

Hashes and measurements: [source-layout evidence](2026-09-14-dac-source-checks.json).
Current artifacts: [hardware checkpoint](CURRENT-HARDWARE.md).

## Remaining release gates

The existing 40 MHz timing budget has only 0.6 ns ideal SCLK pulse-width
reserve before source/PCB effects. This revision changes neither firmware
clock nor manual CS behavior; qualify SCLK/DIN/SYNC/CLR at the DAC pins
under actual rails, temperature and load. Source locality alone cannot
close this gate.

Independent Class 4 shutdown/rearm, RGB reset-off, actual fan/5 V loads,
buck thermal/stability/protection, module pin-grid and antenna/USB mechanics,
BOM/package/assembly review and physical qualification remain open.
KiBot configuration still awaits user direction. No Gerbers generated.

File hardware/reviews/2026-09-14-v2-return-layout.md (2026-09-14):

# V2.0.8 DAC return copper and ESP32 envelope

Based on hardware V2.0.7, commit
`b4385e3a3fff1313cbd545e9392028e87c34ad1a`.
**Engineering draft only — no fabrication or laser-operation approval.**

## User-supplied mechanics

The user reports an ESP32 module body of **28 x 57 mm**, with one 22-pin
male strip on each side. The carrier retains two female 1x22 socket strips.

The old footprint drew a 25.4 x 56 mm body. Both the project-local library
and the placed U1 footprint now draw a 28 x 57 mm F.Fab envelope, a
28.2 x 57.2 mm silkscreen outline and a 29 x 58.54 mm courtyard.
The old courtyard's longer Y allowance is retained. All 44 pads, pin
numbers, drills, nets and absolute contact positions are unchanged.

Body centering on the pin grid is still an assumption. The 2.54 mm pin pitch
and 22.86 mm row-center spacing remain provisional; the user has been asked
for measured row spacing. The outside dimensions alone do not establish
socket fit, USB access, component height or antenna clearance. No antenna
keepout qualification is claimed.

## Placement and local routing

- R26 (0 ohm) moves from (48, 58) to (92.8, 45) mm, toward the MCU/DAC
  boundary. Its pad nets remain AGND and power ground. Its reference label
  moves with it. No additional connection between those two nets is introduced.
- The enlarged module envelope exposed collisions with C_DMXLV1 and
  C_SCANLV1. Both move from x=125.5 to x=128.45 mm and rotate from 180 to
  0 degrees, retaining y=20.85 and y=31.5 mm respectively. Their +3V3 pad
  coordinates stay exactly fixed; only their ground pads change position.
- Ground connections use 0.4 mm F.Cu tracks to 0.60/0.30 mm ground vias:
  C_DMXLV1 has a 1.275 mm link to (131.2, 20.85); C_SCANLV1 has a 4.775 mm
  link to (134.7, 31.5). The existing shared ground route near the scan
  buffer is retained and anchored at (125, 20.85) with a 0.975 mm link.
- Two nearby +3V3 distribution segments are replaced by six short detour
  segments to clear the relocated ground pads. The capacitor-to-buffer VCC
  routing and all signal routes remain unchanged. Three reference labels
  are adjusted in addition to R26.
- Intermediate candidates had courtyard collisions, local shorts and an
  isolated ground branch. These were corrected, not excluded from DRC.

## Return copper

The V2.0.7 back-layer zone outlines left a large MCU-side gap: AGND ended
at x=94 mm; the power-ground zone began at x=124 mm. R26 was remote from
the crossing DAC input traces. Filled copper, not only zone outlines,
showed poor opposite-layer reference coverage along those routes.

Added two local F.Cu ground zones:

| Zone | Net | Outline bounds (mm) |
|---|---|---|
| DAC input return | AGND (from Galvo Board) | x=76–93.35, y=22–54 |
| MCU SPI return | 5V GND Buck | x=93.65–125, y=25–64 |

The zones retain 0.20 mm clearance, 0.25 mm minimum thickness and
0.30/0.40 mm thermal gap/spoke width, with isolated islands removed.
Three AGND stitching vias at (90.5, 26), (86, 30), and (90.5, 43) mm
connect local front/back copper. The three original zone outlines/settings
are preserved; their filled copper is recalculated. There are five ground
zones in total, with the two new zones explicitly named.

The [measurement script](../tests/measure_dac_return_layout.py) samples
trace centerlines at intervals no greater than 0.1 mm and tests for filled
ground polygons on the opposite layer. It includes bias branches; it is
not a point-to-point flight-time or impedance calculation.

| Input net | Total trace length, unchanged (mm) | V2.0.7 overlap | V2.0.8 overlap |
|---|---:|---:|---:|
| DAC_SCLK_3V3 | 37.434 | 1.799% | 75.602% |
| DAC_DIN_3V3 | 29.958 | 2.247% | 74.781% |
| DAC_SYNC_3V3 | 28.971 | 30.157% | 78.571% |
| DAC_CLR_3V3 | 32.983 | 31.869% | 90.677% |

These are geometric overlap estimates, **not proof of a continuous
low-inductance return path**. Split crossing, copper necks, pads, vias,
coplanar return, socket/module ground paths and coupled supply currents
require further review. Timing at the actual SPI rate and EMC remain open.
No arbitrary overlap percentage is used as a production pass threshold.

A 0.05 mm sampling run changes each result by less than 0.3 percentage
points. A query-only negative run with no selected reference-ground nets
reports zero overlap. An earlier in-memory native zone-deletion experiment
segfaulted and is not counted as a passing check; the separate read-only
measurement processes completed successfully. PCB files were not written
by those diagnostic runs.

## Verification and preservation

- All 122 component values/footprint assignments and all 110 electrical net
  memberships exactly match V2.0.7. The schematic changes only revision text.
- 119 component placements remain unchanged; only R26 and the two bypass
  capacitors move. Every pad retains its net, size, drill, shape, attribute
  and UUID. All U1 pad positions and both capacitor VCC positions are preserved.
- 1104 baseline copper objects retain exact geometry, net, width and ID.
  Ten obsolete objects are removed (seven tracks, three vias); fifteen are
  added (nine tracks, six vias). Final board: 1010 segments, 109 vias.
- Unrelated hidden-field font normalization from native save was restored
  before adoption. Project rules and the legacy PCB are unchanged.
- Fresh native ERC: zero violations. DRC with zone refill, all-track checks
  and schematic parity: zero errors/unconnected items, only the known buck
  footprint-type warning and two diode footprint-filter warnings.
- All six interface checkers, 33 unit tests, the draft-evidence guard and
  the existing buck-input/unique-copper-ID guard pass.
- Combined front/back copper, module outline and revised placements were
  rendered and inspected. The overlap measurements reproduce from the
  adopted PCB. Source hashes and detailed figures are in
  [return-checks.json](2026-09-14-return-checks.json).
- A relocated copy of the staged hardware/tests reproduces export/ERC, all
  six interface checkers, 33 unit tests, native DRC/parity/draft and buck
  guards, exact preservation and identical overlap figures. Source hashes
  match the working copy; untracked user files are absent.

Run the read-only geometric measurement with KiCad's Python bindings:

```sh
/usr/bin/python -B hardware/tests/measure_dac_return_layout.py \
  'hardware/schematics/Laser Controllerv2_only_for_pcb_test.kicad_pcb'
```

Use the [current checkpoint](CURRENT-HARDWARE.md) for the full ERC/DRC and
interface-check commands. Firmware, shutdown behavior and KiBot are
unchanged. [Independent shutdown](2026-09-14-shutdown-boundary.md),
actual loads/thermal/EMC qualification, exact socket/module mechanics,
analog/DMX/fan interfaces, BOM/package/assembly and independent physical
review remain release gates.

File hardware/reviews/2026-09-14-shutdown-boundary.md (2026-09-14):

# Shutdown boundary review — 2026-09-14

**V2.0.7 remains a routing draft, not approved for fabrication or laser operation.**

This review corrects unsupported safety claims and records the implemented
shutdown boundary. It does not modify firmware, schematic, PCB, project rules
or KiBot. An existing external safety circuit may provide additional functions;
its presence, wiring and effectiveness have not been established.

## Audited baseline

Hardware commit: `b4385e3a3fff1313cbd545e9392028e87c34ad1a`,
tag `hw-v2.0.7-draft`. See [current hardware](CURRENT-HARDWARE.md)
for PCB geometry, prior ERC/DRC results and remaining warnings.

SHA-256 of the audited sources:

| Source | SHA-256 |
|---|---|
| V2 schematic | `e92f80b2c2eb07ac488f8748f1e45c8cb046f8f230c9b9100198b0ece4ccb37f` |
| V2 PCB | `8f4477ad75fe0f7b1899dd8e1304cf1b2b0bf4cbaac3f3813b198176316e91c2` |
| V2 project | `dc77f4155067018d81c509e667ad67642031a5cf69abe7181144c19c11bd3b1b` |
| `src/safety/safety.cpp` | `9b31677856e685004505bc0fad81e5df602963d77c1a7d5ca40d551c0aa899b2` |
| `src/safety/safety.h` | `dd11e8789a719ee8041625a845b65d37b38cefca5ece28e57a240eff89d60135` |
| `include/pinmap.h` | `d6bda116a6d631f1d99485a5187ec3d1900ed9de9981b21e98ec86a3be1f4835` |

## Schematic boundary

A fresh KiCad XML export contains 122 components and 110 nets. Relevant
memberships, confirmed from that export:

| Net / connection | Endpoints |
|---|---|
| `/GPIO47` | J_ESTOP1.1 → U1.J2_17 (GPIO47) |
| `/GPIO38` | U1.J2_10 (GPIO38) → U_WD1.4 (active-low reset) |
| `/GPIO14` | U1.J1_20 (GPIO14) → C_TRIGC_WD1.1 (watchdog trigger coupling) |
| `/WD_OUT` | U_WD1.3 → R_SSRCTRL1.1 |
| `/SSR1_CTRL` | R_SSRCTRL1.2 → J_SSR1.1 |
| `5V GND Buck` | J_ESTOP1.2 and J_SSR1.2; also U15.3 and U15.5 |

R_SSRCTRL1 is 330 ohm. U_WD1 is an NE555D. J_SSR1 is a control
connector, not an identified or qualified energy-interruption device.
No direct E-stop-to-SSR hardware gate is shown. GPIO38 controls the
watchdog timer's reset; a separate timer alone does not establish
firmware-independent enforcement of the E-stop or other status inputs.

U_SCAN1 monitors electrical command activity. It does not measure actual
mirror motion. Its buffered GPIO39 interface protects the MCU input but
does not qualify stationary-beam detection. See the
[scan-status review](2026-09-14-v2-scan-status.md).

## Firmware decisions and isolated reproduction

Sources: [safety.cpp](../../src/safety/safety.cpp), especially `init()`,
`allOk()`, `emergencyStop()` and `task());
[pin assignments](../../include/pinmap.h).

The [host decision probe](2026-09-14-shutdown-probe.cpp) embeds the two
decision functions verbatim and the E-stop sampling expression. GPIO,
logging, software-watchdog and subsystem status are stubbed. Assertions
reproduce the current behavior, including unsafe cases; they are
**diagnostic evidence, not desired safety requirements or a release gate**.

| Stimulus | Override disabled | Override enabled |
|---|---|---|
| ARM false, other inputs healthy | Enable decision false | Enable decision false |
| ARM true, one of E-stop/scan/software-watchdog/subsystem status false | Enable decision false | Enable decision true |
| That status becomes healthy again, ARM still true | Enable decision true without a new ARM request | Enable decision true |
| `emergencyStop()`, ARM initially true | Immediate GPIO38 LOW; ARM cleared; next decision false | Immediate GPIO38 LOW; ARM retained; next decision true |
| E-stop input HIGH / LOW | HIGH accepted / LOW rejected by sampling rule | Same sampling rule, but status bypassed in enable decision |

Each of the four status faults was tested separately. The input/decision path
in `task()` samples status and applies `allOk()` without clearing the ARM
request. Thus recovery of a status input can permit automatic re-enable even
with override disabled; a status trip is not equivalent to a call to
`emergencyStop()`. Other concurrent firmware actions can change ARM, but
the examined path does not itself enforce latched shutdown/manual rearm.

`init()` enables the E-stop pull-up. An open/broken wire that consequently
reads HIGH is accepted, not diagnosed as a trip. Initialization later writes
GPIO38 LOW; this does not prove OFF before initialization or during reset,
brownout or partial power. The task continues generating GPIO14 heartbeat
activity while running, including when override bypasses status conditions.

The nominal 20 ms task delay is not a measured or guaranteed shutdown time.
This probe is not a complete firmware build, scheduler/concurrency test,
electrical simulation, physical test or safety certification.

Reproduce from the repository root with a C++17 compiler (assertions enabled):

```sh
shutdown_probe_dir=$(mktemp -d /tmp/galvos-shutdown-probe.XXXXXX)
g++ -std=c++17 -Wall -Wextra -Werror -O0 \
  hardware/reviews/2026-09-14-shutdown-probe.cpp \
  -o "$shutdown_probe_dir/probe"
"$shutdown_probe_dir/probe"
```

This is a dated source snapshot. If firmware changes, compare the embedded
functions and sampling expression to the new source before interpreting it.

## RGB and thermal qualifications

For the stated active-HIGH laser driver and adequate optocoupler LED current,
GPIO HIGH → 6N137 output LOW → laser TTL OFF. A larger HIGH duty therefore
means more OFF time. A 10 kohm GPIO pull-up cannot guarantee the required
6N137 LED current; the maximum even before LED/series voltage drops is only
3.3 V / 10 kohm = 0.33 mA. Do not claim a reset-OFF guarantee from those
pull-ups. Shared input/output ground (e.g. U15.3 and U15.5) also prevents
claiming galvanic isolation merely because optocouplers are present.

[Temperature monitoring](../../src/sensors/temp_monitor.cpp), protection
action around lines 333–340, explicitly calls `safety::requestArm(false)`
for both alert and critical conditions. This action clears ARM regardless
of override; the retained-ARM finding above must not be generalized to it.
Temperature protection still depends on software and sensor qualification.

## Documentation correction and release decisions

README, introduction, troubleshooting and glossary now distinguish observed
monitoring behavior from unproven independent shutdown. Corrected claims
include RGB polarity, reset-OFF, optocoupler isolation, E-stop wire-break
handling, actual mirror sensing and the alleged software independence of
the timer chain. Historical design-intent comments in `safety.h` and
`pinmap.h` are not proof of an installed physical interlock chain; firmware
files and user-owned `agents.md` were not changed.

Before choosing or approving a safety circuit, obtain:

- Wiring/photo or circuit diagram of the existing external E-stop, key and
  enclosure contacts, including contact type and normal/failed states.
- Exact SSR/relay/power-switch model, terminals, supply and the rail it
  interrupts; how hazardous emission is inhibited if the switch fails.
- Any independent safety controller, shutter and actual mirror feedback,
  with their interface and fault-response specifications.

The resulting system must have a qualified firmware-independent,
default-OFF emission-inhibit path; defined response to wire breaks,
reset/brownout/partial power and relevant single faults; latched trip and
deliberate manual rearm; and qualified switching and scan-safety behavior.
Required shutdown time, diagnostics and architecture must be established
by the system risk assessment and independent competent review, not inferred
from this logic probe. No safety rating or approved replacement circuit is
claimed here.

Keep emission physically inhibited during bring-up. The remaining
[PCB plan](2026-09-14-v2-pcb-plan.md), power/thermal/mechanical work and
physical verification are still required. KiBot's separately proposed
[workflow correction](2026-09-14-kibot-ci.md) remains awaiting direction.

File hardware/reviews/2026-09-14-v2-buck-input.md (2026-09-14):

# V2.0.7 local buck input capacitor

Based on V2.0.6 commit `5cde493a24aa4732153044ad6434225d27abd20a`.
**Engineering draft only; no fabrication or laser-operation approval.**

## Input-loop change

TI LMR33630 SNVSAN3F section 10.1 identifies the input capacitor/regulator
power-ground loop as the critical high-transient-current loop and calls for
short, wide routing with nearby input capacitors. The inspected reference is
<https://www.ti.com/lit/ds/symlink/lmr33630.pdf>, SHA-256
`3b0920a4e56a0b3f5f214a6317d3c06cff6e541e5054024adc31c30acc50c04a`.

C_IN2 was at (146, 31) mm, with its input connection reaching the IC through
the back-layer distribution and vias. It now sits at (136.5, 38.73) mm,
rotated 90 degrees, next to the existing C_INHF1. Its 10 uF value and 1210
footprint are unchanged. C_IN1 remains the other input-bank capacitor.

The new C_IN2-to-C_INHF1 VIN and ground links are 3.5 mm long, 0.8 mm wide,
and on F.Cu. They join the existing 0.6 mm direct C_INHF1-to-regulator paths.
Each complete capacitor-pad-to-IC-pad path is 6.905 mm long, without a via.
These numbers describe explicit trace centerlines, not measured inductance,
current distribution, loop area or an EMI result. The source-distribution
traces upstream of the local input capacitor are retained.

Four obsolete top-layer capacitor stubs and their two now-unused vias were
removed. Two reference labels were adjusted. No electrical net, component
value, footprint type, firmware behavior or external connector changed.

## Duplicate-object correction

The stricter native object audit found two exact +3V3 trace pairs sharing IDs
in the published V2.0.5 and V2.0.6 PCBs. V2.0.4 had distinct IDs; the V2.0.5
restoration mapped pre-existing coincident geometry to the same IDs. Earlier
geometry-count comparisons did not check UUID uniqueness, and native DRC did
not report this condition. This is a correction to that verification gap.

The pairs were at (85.5913, 39.0662) to (87.5251, 41) mm, and the adjacent
(85.5912, 39.0662) to (85.5913, 39.0662) mm stub. One identical copy of each
is removed; one remains with the same geometry, width, net and ID. The
occupied +3V3 copper and its connectivity are unchanged. The local input
layout checker now rejects duplicate IDs across all tracks and vias.

## Proof

- All 122 component values/packages and all 110 electrical net memberships
  exactly match V2.0.6; only the schematic revision text changes.
- Native comparison confirms 121 unchanged placements and every pad's net,
  size, drill, shape and attribute. Only C_IN2 is moved/rotated.
- Of 1120 old copper objects, six obsolete input-capacitor objects and two
  exact duplicate copies are removed; 1112 distinct objects retain their
  original geometry, width, net and ID. Two new local tracks are added.
- Final board: 1008 segments, 106 vias, three filled/named ground zones.
  The front-layer detail was rendered and inspected. No autorouter used.
- Fresh ERC: zero findings. Native all-track DRC/refill/parity: zero
  unconnected items, no errors, only the known buck-type warning and the two
  known diode-filter warnings. No rules/severities/exclusions changed.
- All six interface checkers and 33 unit tests pass. A new native layout
  guard checks both direct input paths, widths, lengths and copper-ID
  uniqueness. Negative runs reject the duplicate-ID baseline and a candidate
  missing its local VIN link. The guard's 8 mm/0.60 mm bounds are local
  regression constraints, not TI-specified limits or current ratings.
- A relocated staged copy reproduces export/ERC, all six interface checkers,
  33 tests, native layout/ID and DRC/parity guards, and exact preservation.
  The KiCad source/project files match byte-for-byte. Publication details are
  recorded in `codex-todos.md`; source hashes and commands are in
  [CURRENT-HARDWARE.md](CURRENT-HARDWARE.md).

The earlier V2.0.6 feedback/bypass change remains intact. Laser safety,
exact DevKit/socket/antenna mechanics, actual load currents, component MPNs
and capacitor effective capacitance, source protection, copper/thermal
capacity, load-step/loop-stability behavior and EMC remain unqualified.
Moving a nominal 10 uF capacitor does not establish its capacitance at bias
or qualify a 3 A supply. KiBot inputs remain unchanged pending approval.

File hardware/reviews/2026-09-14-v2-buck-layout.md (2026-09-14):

# V2.0.6 buck feedback and bypass correction

Based on V2.0.5 commit `bf13b4b959f2df56b4617303c9e3c50e2a72675f`.
**Engineering draft, not approved for fabrication or laser operation.**

## Evidence and design scope

The earlier [power audit](2026-09-14-power-path.md) identified incomplete
component ratings and the 100 nF / 220 nF input-bypass discrepancy. The current
routed board additionally had 23.655 mm of FB-net copper distributed across
both layers with two vias. Its feedback divider was well away from the FB pin.

The manufacturer's LMR33630 datasheet, SNVSAN3F, was downloaded again from
<https://www.ti.com/lit/ds/symlink/lmr33630.pdf>. It matches the previously
inspected file: SHA-256
`3b0920a4e56a0b3f5f214a6317d3c06cff6e541e5054024adc31c30acc50c04a`.
Sections 9.2.2.6 through 9.2.2.8 specify the local ceramic capacitors;
section 10.1 calls for a close feedback divider, short FB/ground connections,
short/wide BOOT and VCC routing, and small input switching-current loops.

V2.0.6 addresses the local bypass specifications and feedback routing. It does
not qualify or redesign the entire input hot loop, output capacitor bank,
inductor, input protection, copper weight or thermal structure.

## Circuit and BOM

- C_INHF1: 100 nF becomes **220 nF, 50 V, X7R, 10%**, retaining its 1206 footprint
  and VIN-to-power-ground connection. The 220 nF/50 V/X7R specification follows
  TI's DDA guidance; it is not an added parallel capacitor.
- C_BOOT1: retains 100 nF/1206; specifies ceramic X7R, 16 V, 10%. TI requires
  at least 10 V. C_VCC1 retains 1 uF/1206 and specifies 16 V X7R, 10%.
- R_FB1/R_FB2 retain 100 kohm / 24.9 kohm, 1%, and their 1206 footprints.
  Layout requirements and explicit tolerance fields are recorded.
- No component is added or removed. All 122 components and 110 electrical
  net memberships are retained, with only C_INHF1's nominal value changed.
  Firmware, connectors, power topology, fan rails and safety logic are unchanged.

These fields specify procurement requirements, not selected capacitor MPNs.
Effective capacitance/bias/temperature, inductance/current ratings and actual
load response still require component selection and qualification.

## PCB change and preservation

| Item | V2.0.5 | V2.0.6 |
|---|---|---|
| Total FB trace centerline length | 23.655 mm | 6.550 mm |
| FB vias / layers | 2 / F.Cu and B.Cu | 0 / F.Cu only |
| R_FB1 center / orientation | (151, 51) mm / 0 degrees | (149, 48) mm / 90 degrees |
| R_FB2 center / orientation | (145, 51) mm / 0 degrees | (145.25, 44.5) mm / 180 degrees |
| BOOT/VCC trace widths | 0.25 mm | 0.40 mm |
| Board segments / vias | 1017 / 111 | 1012 / 108 |

The bottom feedback resistor returns locally to the exposed-pad ground.
The top resistor senses the existing output branch, away from the SW node;
the longer output-sense connection is not part of the high-impedance FB node.
The old ground spur, two FB vias and one ground via are removed. The short
BOOT/VCC paths retain their positions and receive wider copper.

Native comparison confirms 120 unchanged placements, all original footprint
types, pad dimensions/drills/shapes and pad nets. Of 1128 baseline copper items,
1108 retain exact geometry and width, 17 obsolete FB/ground/stub items are
removed, and three BOOT/VCC segments are widened. Nine new F.Cu segments stay
within x=143..152 mm, y=41..50 mm. Three named ground zones remain filled.
Only three reference labels are adjusted for the moved parts and bypass area.
No autorouter was used for this change.

The initial candidate left a 0.5 micrometer orphan stub and a reference-label
collision. These were corrected before adoption; no rule exclusions were added.

## Proof and limits

- Fresh export: unchanged net membership and exactly the approved value change
  against V2.0.5. The buck checker enforces the feedback ratio, BOOT/SW/VCC
  connectivity, power-ground separation, bypass values/packages and ceramic fields.
- Six interface checkers and 33 test methods pass. The five new buck methods
  include a valid case, old 100 nF rejection, changed feedback ratio, five wrong
  power/feedback/thermal-pad pin connections and an under-rated bypass capacitor.
- ERC: zero findings. Native DRC with refill, all-track checks and schematic
  parity: zero unconnected items, no errors, only the known buck footprint-type
  warning and two diode footprint-filter warnings. Draft guard passes.
- The project rule file is byte-identical to V2.0.5. The legacy PCB, firmware
  and KiBot workflow/configuration are unchanged. The front-layer detail was
  rendered and inspected. A relocated staged copy also passes export/ERC,
  all six interface checks, 33 tests, DRC/parity/draft guard and the native
  preservation comparison. Its KiCad source/project files are byte-identical.

See [CURRENT-HARDWARE.md](CURRENT-HARDWARE.md) for source hashes and commands.
To prove the electrical delta, also provide the V2.0.5 XML export to
`python hardware/tests/check_buck_interface.py AFTER.xml V205.xml`.

This is a layout/bypass improvement, not a power-supply release. Actual maximum
5 V load, 12 V fan currents, input range/fault behavior, capacitor/inductor MPNs,
effective capacitance, current capacity, input hot loop, thermal operation,
loop stability, EMC and physical testing remain open. The earlier audit's
10..30 V calculations are historical illustrations, not the currently confirmed
12.6 V nominal input contract. Independent Class 4 shutdown/rearm and all other
electrical/mechanical release gates remain unresolved.

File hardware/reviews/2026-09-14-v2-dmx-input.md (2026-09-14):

# V2.0.5 DMX receive input protection

Engineering checkpoint: `hw-v2.0.5-draft`, based on V2.0.4 commit
`61b6e558cb0eea339cc00c05baf04d4f877b6e2a`.
**NOT FOR FABRICATION OR LASER OPERATION.**

## Cause and bounded change

The 5 V-powered DMX module's RO pin previously drove ESP32 GPIO4 directly.
The exact module is not qualified, so a 3V3-compatible RO high level could not
be assumed. As for scan status, a noninverting SN74LVC1G17DBVR buffer now separates
the module output from the MCU voltage domain. This is not galvanic isolation.

| Connection | V2.0.5 contract |
|---|---|
| J_DMX1.1 | Existing Buck +5V, unchanged |
| J_DMX1.2 | MCU power ground, unchanged |
| J_DMX1.3 | `/DMX_RO_5V`: U_DMXLV1.2 and R_DMXIN1.1 |
| J_DMX1.4 | NC, unchanged |
| U_DMXLV1.4 | `/GPIO4`: U1.J1_4 only |
| U_DMXLV1.5 / C_DMXLV1.1 | MCU +3V3 |
| U_DMXLV1.3 / C_DMXLV1.2 / R_DMXIN1.2 | MCU power ground, not AGND |
| U_DMXLV1.1 | NC |

Added parts: U_DMXLV1, SN74LVC1G17DBVR, SOT-23-5;
R_DMXIN1, 10 kohm, 1%, 0.25 W, 1206;
C_DMXLV1, 100 nF, X7R, 50 V, 10%, 1206.
Manufacturer/MPN and passive requirements are recorded in the schematic and PCB.
No existing connector, firmware, GPIO assignment, shutdown or arming logic changed.

## Electrical envelope and remaining qualification

Reference: Texas Instruments SN74LVC1G17 datasheet SCES351Y, revised October 2025:
<https://www.ti.com/lit/ds/symlink/sn74lvc1g17.pdf>.
Inspected reference SHA-256:
`c76fa723fac4502423967a1aa087dd669106b52b8de620c024b26e56f5d59309`.

- Recommended input range is 0 to 5.5 V, independent of its 3V3 supply.
  This does not permit 12.6 V or arbitrary cable transients.
- Ioff is at most 10 microamp at VCC = 0; input leakage at most 5 microamp.
  A 10 kohm, 1% pull-down bounds leakage-induced voltage to 50.5 mV.
  At 5.5 V it loads RO by at most 0.556 mA and dissipates about 3.06 mW.
- The 3.0 V VCC test row gives positive threshold 1.48 to 1.92 V and negative
  threshold 0.89 to 1.20 V. Do not extrapolate that row into a guarantee over
  every actual 3V3 supply/temperature corner. Qualify the module's RO levels,
  drive strength and waveform under the added load against the full datasheet.
- DBV pinout: 1 NC, 2 A, 3 GND, 4 Y, 5 VCC; noninverting Schmitt input.
  Nanosecond-scale propagation is small relative to a 4 microsecond DMX bit,
  but does not substitute for waveform/timing measurements.
- A pull-up to 3V3 could inject current into that rail from a 5 V RO signal;
  a pull-up to 5 V could backfeed an unpowered external module. The pull-down
  avoids those bias paths and gives LOW/break when disconnected, not UART idle HIGH.

The current receive-only firmware uses UART1/GPIO4 and rejects size <= 0 or
packets with an error. Only accepted packets update the DMX receive timestamp.
Holding RX LOW is not a valid DMX packet and is not an independent laser-off
command. Hardware timeout/safety behavior still requires physical verification.
The firmware's short-frame/start-code handling and its initial receive timestamp
also need separate review; this checkpoint makes no DMX parser-safety claim.

The exact MAX485 module circuit/MPN, RO voltage envelope, enable wiring, bus bias,
termination, isolation, cable shielding and ESD protection remain unqualified.
A MAX485 module is not proven equivalent to a particular manufacturer's IC merely
by its sales name. Attempts to retrieve the MAX485 manufacturer PDF did not
succeed; no new MAX485 datasheet guarantee is claimed here.
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

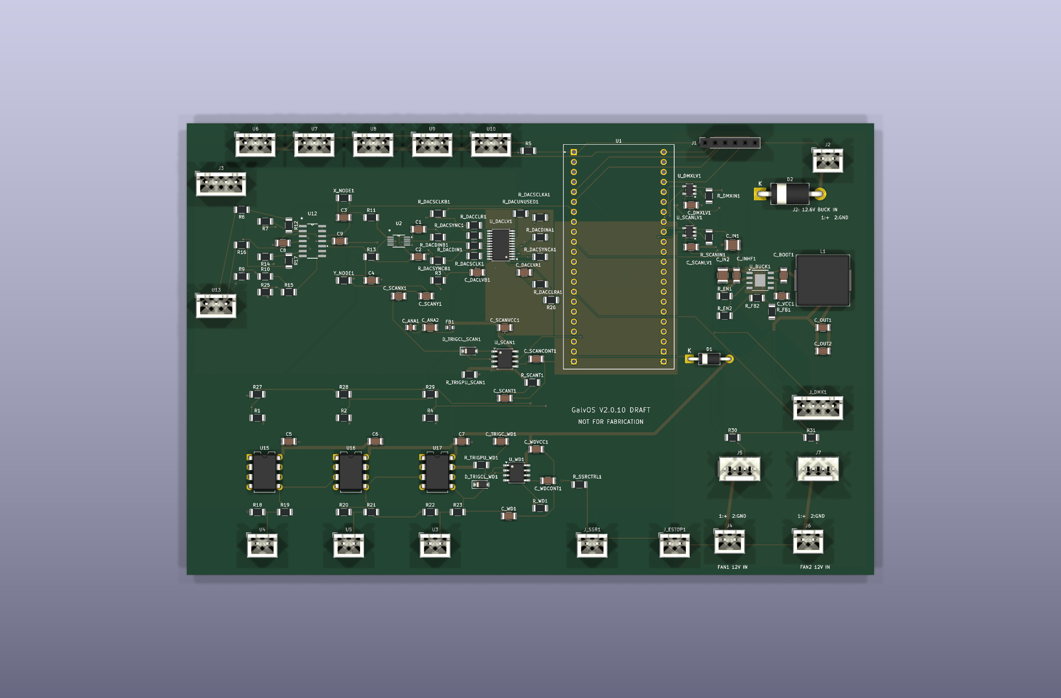
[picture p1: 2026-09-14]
hardware/GalvOS_V2.0.10_PCB_Top.png

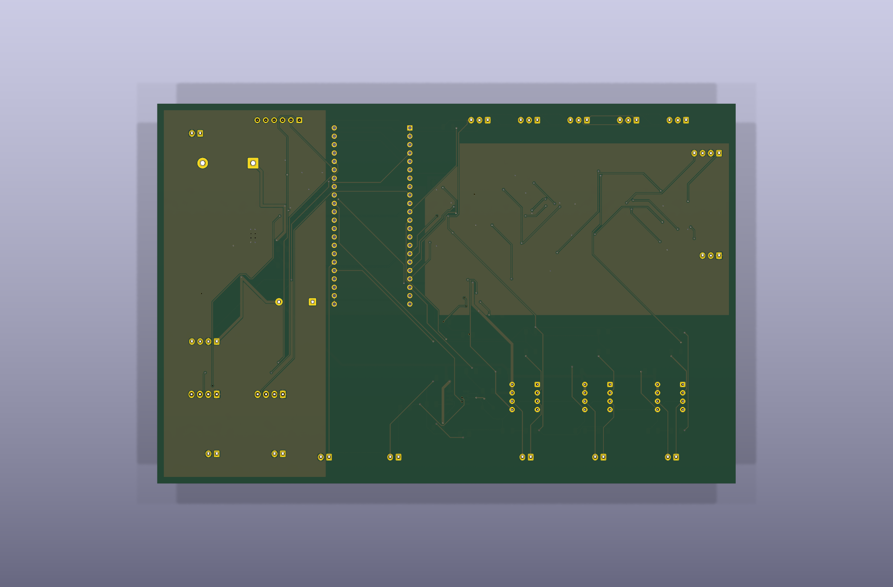
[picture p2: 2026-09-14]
hardware/GalvOS_V2.0.10_PCB_Bottom.png

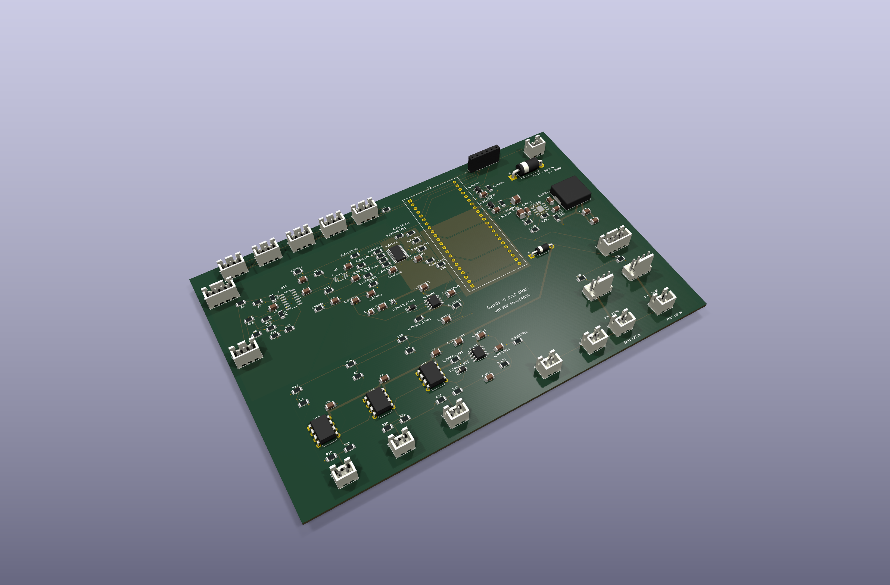
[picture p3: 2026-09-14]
hardware/GalvOS_V2.0.10_PCB_Perspective.png

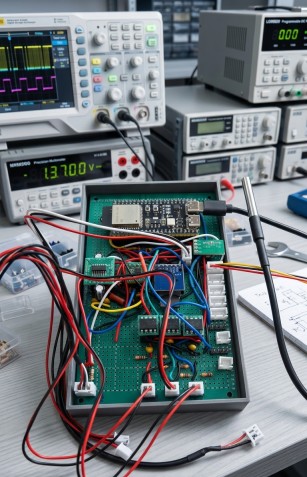
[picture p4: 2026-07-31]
docs/assets/photos/prototype_board.jpg

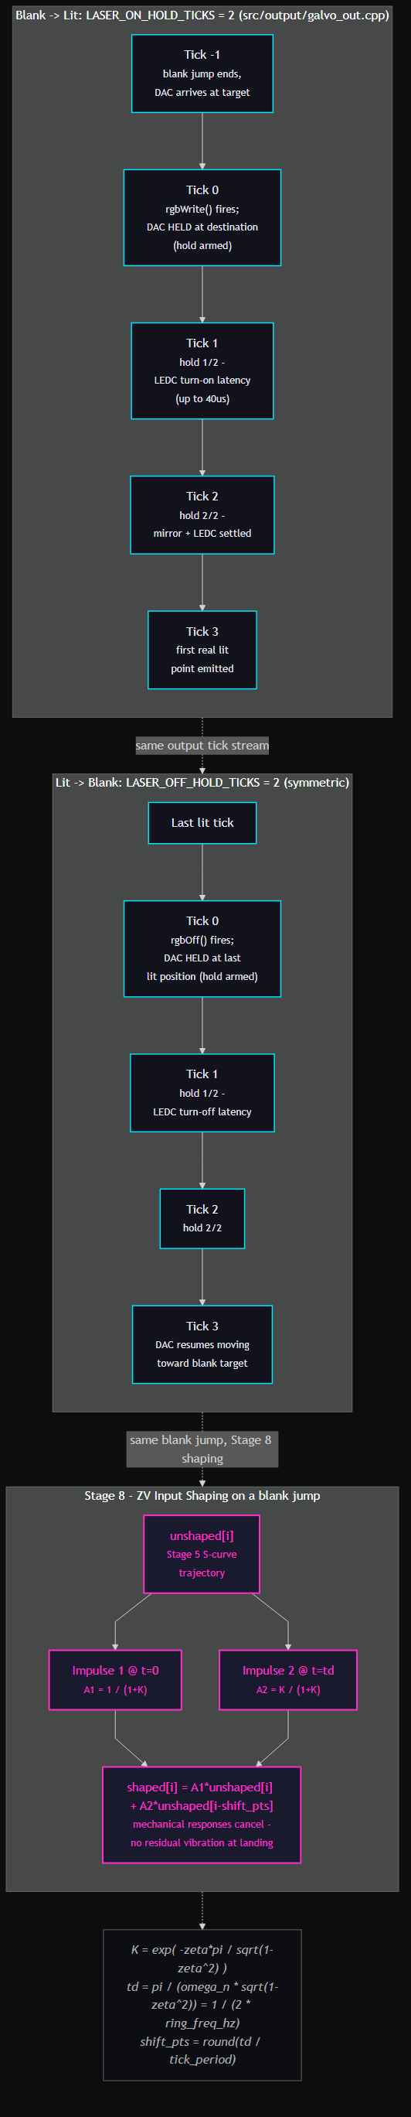
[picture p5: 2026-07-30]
docs/assets/diagrams/laser_timing.png

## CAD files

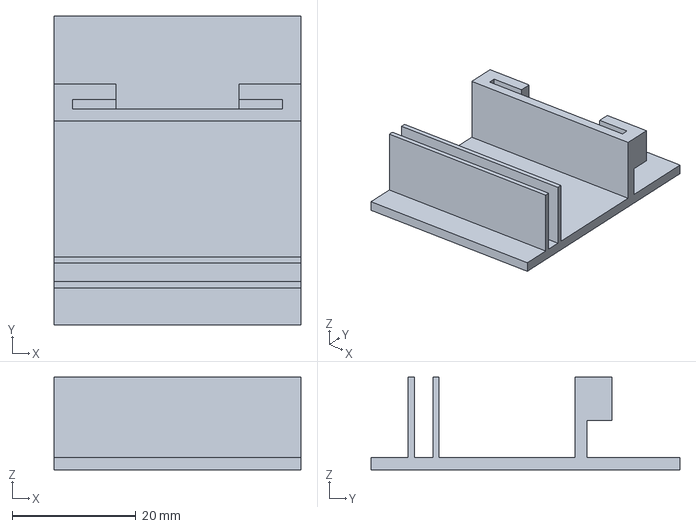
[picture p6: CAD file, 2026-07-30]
hardware/3DPrints/CAM Module Holder v2.3mf
40.0 x 50.0 x 15.0 mm

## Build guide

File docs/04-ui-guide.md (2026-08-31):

# Chapter 4 — UI Guide

*Previous: [Chapter 3 — Build & Configuration](03-build-and-config.md)*

The GalvOS WebUI is a single-page application served directly from the ESP32's LittleFS flash. No internet connection required, no app to install — open a browser and go.

## Table of Contents

- [Accessing the WebUI](#accessing-the-webui)
- [Installing as a PWA](#installing-as-a-pwa)
- [General Layout](#general-layout)
- [Themes](#themes)
- [Monitoring Popup Window](#monitoring-popup-window)
- [Tab: Dashboard](#tab-dashboard)
- [Tab: Presets](#tab-presets)
- [Tab: Preset Manager](#tab-preset-manager)
- [Tab: DMX Live](#tab-dmx-live)
- [Tab: Text](#tab-text)
- [Tab: Paint](#tab-paint)
- [Tab: ILDA / SD](#tab-ilda--sd)
- [Tab: Calibration](#tab-calibration)
- [Tab: Optimizer](#tab-optimizer)
- [Tab: Projection](#tab-projection)
- [Tab: Thermal](#tab-thermal)
- [Tab: Log](#tab-log)
- [Tab: Configuration](#tab-configuration)

> **A note on screenshots:** captured live from a running device via `scripts/capture_screenshots.py`, which also redacts IP/hostname/credential fields before saving. The UI is under active development, so individual cards may have moved since a screenshot was taken.

---

## Accessing the WebUI

GalvOS tries to join the configured Wi-Fi network first. If no credentials are stored, or the network does not answer within the connect timeout, it additionally opens its own access point (the STA side keeps retrying in the background, so it will hop onto your network on its own once that comes back):

- **SSID:** `Laser-XXXX` — `XXXX` = the last four hex digits of the chip's MAC address
- **Password:** the next eight hex digits of the same MAC (printed in the serial boot log)
- **IP address:** `192.168.4.1`

Open `http://192.168.4.1` in any browser and configure your network under Configuration → WiFi Connection. Once connected, GalvOS is reachable at its DHCP address — or at `http://galvOS.local` on networks that support mDNS (the hostname is configurable).

> **Tip:** The IP address is always shown on the Dashboard tab under System → IP Address, and in the serial boot log.

A browser-only demo/simulation of the UI runs at [www.galvos.de](https://www.galvos.de).

---

## Installing as a PWA

GalvOS ships as a Progressive Web App (PWA). This means you can install it on your device's home screen and launch it like a native app — no browser chrome, full screen, offline-capable UI.

**On Android (Chrome):**

1. Open the WebUI in Chrome.
2. Tap the three-dot menu → "Add to Home screen".
3. Confirm. The app icon appears on your home screen.

**On iOS (Safari):**

1. Open the WebUI in Safari.
2. Tap the Share button (box with arrow) → "Add to Home Screen".
3. Confirm.

**On Desktop (Chrome/Edge):**

1. Look for the install icon in the address bar (a small computer with a download arrow).
2. Click it and confirm.

---

## General Layout

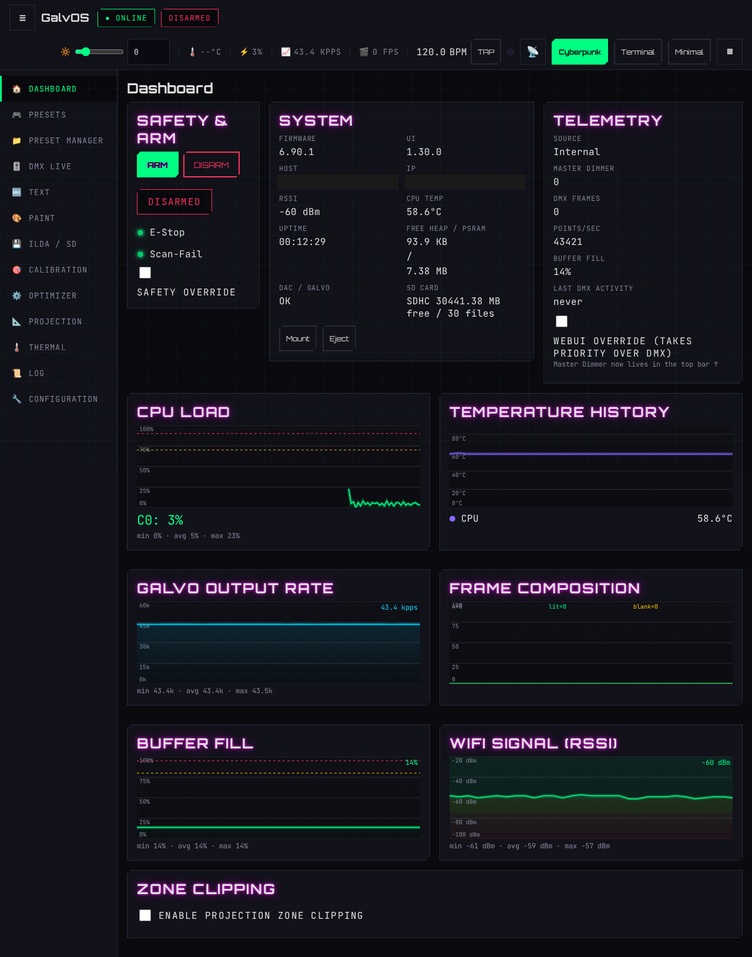
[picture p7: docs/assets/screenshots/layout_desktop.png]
General layout, desktop


The UI is a responsive shell around 13 tabs: a **collapsible sidebar** for tab navigation on desktop, a **bottom tab bar** on mobile, and a **content area** in the middle. All tabs are accessible at any time — switching tabs does not stop the laser or change the active pattern.

The **top bar** stays pinned while you scroll and carries the controls that must never be more than one glance away:

- **ARM / DISARM** — the laser arm control lives here, on its own always-visible row, guaranteed on screen at every viewport width from 320 px up. It is the one control you must never have to hunt for on the phone you're holding during a show.
- **Master Dimmer** — global brightness as a top-bar chip, visible even on the narrowest mobile layout.
- **Status dots** — beam, E-Stop, scan-fail, sequencer beat, and Wi-Fi state, each with proper `role=status`/`aria-label` for screen readers.
- **📡 Open Monitoring window** — opens the read-only [monitoring popup](#monitoring-popup-window) in a separate browser window.
- The **safety banner** (shown when an interlock trips) stacks above the top bar instead of fighting it for the same pixels.

The page title shows both version numbers as `FW: x.y.z - UI:X.Y.Z`. The WebUI carries its own version (`UI_VERSION`), independent of the firmware — flashing only the filesystem changes one and not the other, so "which UI build am I actually looking at" has an answer.

Touch targets (small buttons, checkbox/radio rows) meet the 44×44 px minimum for live/mobile control.

---

## Themes

The WebUI ships **three switchable themes**, driven by a CSS custom-property token engine:

- **Cyberpunk / Glitch** (default) — neon glow, scanline decor, chromatic-aberration accents. The classic GalvOS look, turned up.
- **Terminal CLI** — pure black, zero border radius, box-drawing card headers. For people who think a laser controller should look like `htop`.
- **Minimalist Dark** — no glow, no decor, just controls. The theme you switch to when someone serious is watching.

Pick a theme via the theme buttons in the navigation. The choice persists in the browser's localStorage and is applied by an inline boot script before first paint — no flash of the wrong theme on reload. Colors that encode real meaning (sensor chart lines, log severity, laser color swatches) are deliberately identical across all themes.

---

## Monitoring Popup Window

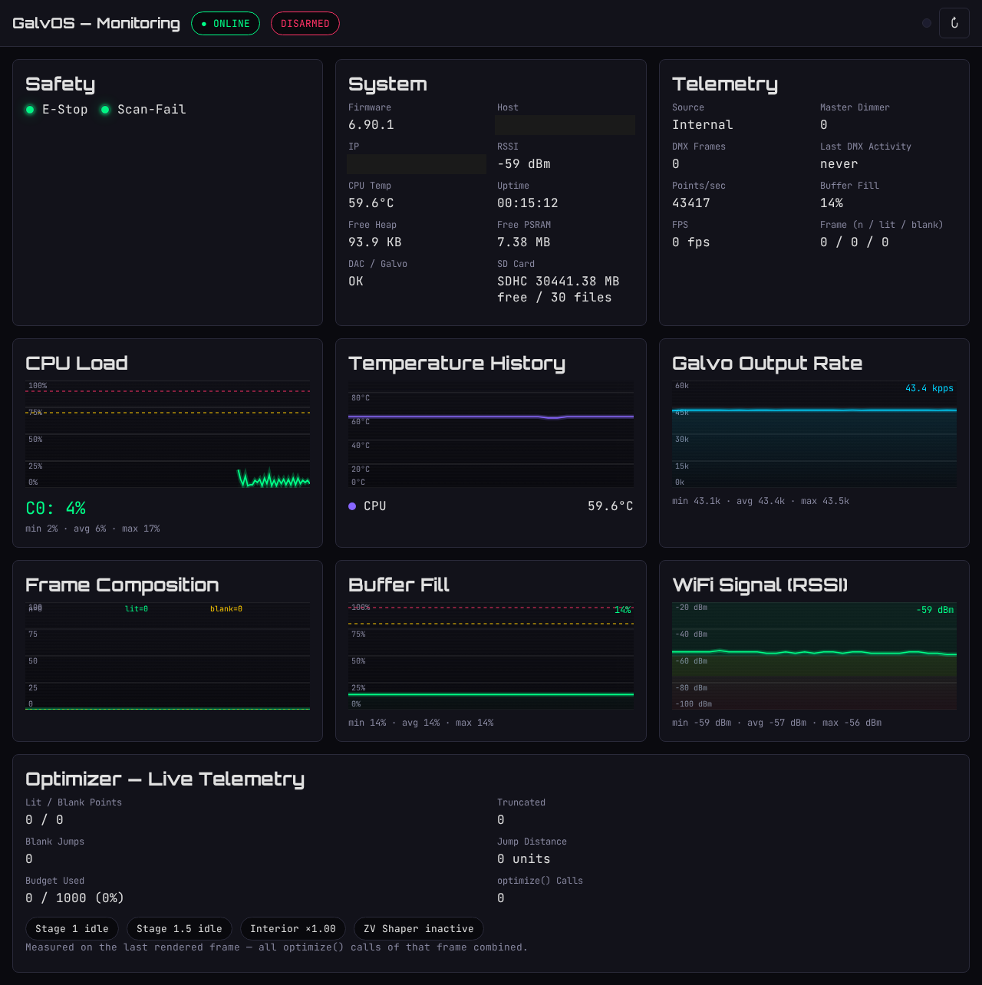
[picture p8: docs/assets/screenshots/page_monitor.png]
Monitoring popup window


A second, read-only page (`monitor.html`) opened via the **📡** button in the top bar, so the show can run full-screen on the main display while the numbers watch themselves on a second monitor. It never sends a write API call — no ARM/DISARM, no sliders, nothing that touches the pattern engine — it only polls the same status endpoints the Dashboard does.

It carries its own connection/armed-state pills, a Safety card (E-Stop/Scan-Fail LEDs, fault reason, override warning), System and Telemetry field grids, the same six scrolling charts as the [Dashboard tab](#tab-dashboard) (CPU Load, Temperature History, Galvo Output Rate, Frame Composition, Buffer Fill, WiFi Signal), the Optimizer's [Live Telemetry](#live-telemetry) block, and a mirror of the current preset + log tail in its sidebar. Since it is a plain `window.open()` popup rather than a tab, it keeps running — and polling — independently of whatever tab is active in the main window.

---

## Tab: Dashboard

The Dashboard is the home screen and the first thing you see on load. It is **status and monitoring only** — everything you *operate* (Preset Grid, Modulators, Color Override, Sequencer transport, BPM Clock, Countdown Timer) lives on the [Presets tab](#tab-presets), and ARM/DISARM plus Master Dimmer live in the always-visible top bar. The top row holds Safety & Arm, System, and Telemetry side by side.

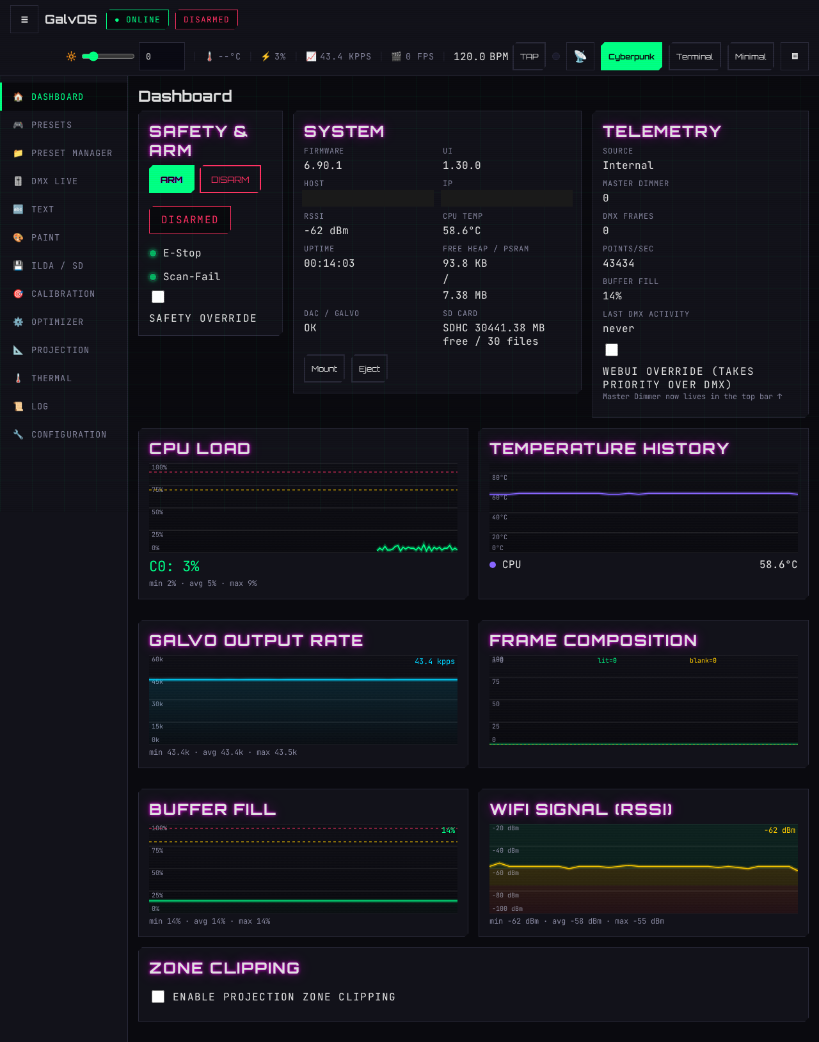
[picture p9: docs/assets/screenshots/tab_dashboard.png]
Dashboard tab


### Safety & Arm Card

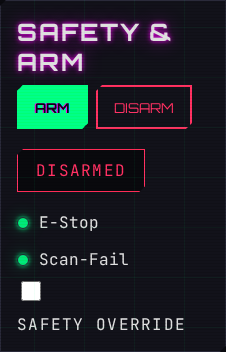
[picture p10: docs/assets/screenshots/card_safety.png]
Safety & Arm card


Shows the state of the hardware safety interlocks:

- **ARM pill** — current armed state at a glance (the actual ARM/DISARM buttons are in the top bar).
- **E-Stop** — green LED: E-Stop circuit is closed (not pressed), system can arm. Red: E-Stop is active, laser cannot arm.
- **Scan-Fail HW** — green LED: the NE555 scan-fail circuit is detecting DAC activity. Red: scan-fail triggered (galvo has stopped or firmware hung).
- **Fault reason** — if the system refused to arm, a text line appears here explaining which condition failed. This reads from the RTC memory value that survives restarts.
- **Safety Override checkbox** — mirrored with the Configuration tab's own checkbox, so you don't have to leave the Dashboard to toggle it (you still shouldn't toggle it casually — see [Configuration → Safety](#safety-configuration)).

### Telemetry Card

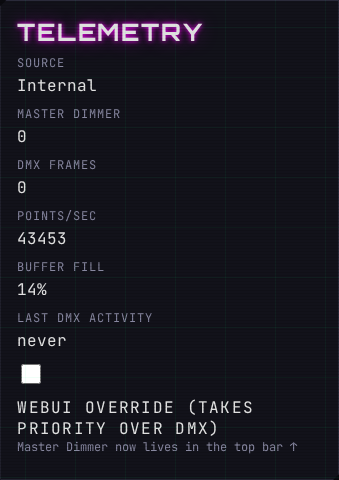
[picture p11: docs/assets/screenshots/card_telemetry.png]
Telemetry card


Live readouts updated every second:

- **Source** — which control input is currently driving the output: `WebUI`, `DMX`, `Art-Net`, `Ether Dream`, `Helios`, `sACN`, `OSC`, or `Internal` (preset).
- **Master Dimmer** — effective master brightness (0–255), combining DMX CH1 and the WebUI override.
- **DMX Frames** — running count of DMX frames received. Useful to confirm DMX signal is arriving.
- **Galvo Rate** — current output rate in points-per-second with a visual bar. The bar fills relative to the configured `galvo_kpps` maximum.
- **Buffer fill level** — how full the DAC output ring buffer is. Sustained overflows cause flicker and are visible as "Ring buffer overflow" in the log.
- **Last DMX activity** — time since the last DMX frame arrived. Goes red if DMX signal is lost.
- **WebUI Override checkbox** — makes the WebUI take priority over DMX/Art-Net.

The six charts below sit together in one grid (three columns on a wide screen, collapsing to two then one as the viewport narrows). The four single-metric ones (CPU Load, Galvo Output Rate, Buffer Fill, WiFi Signal) each get a min/avg/max readout under the chart, over whatever span is currently on screen; the two multi-series ones (Temperature, Frame Composition) skip it, since a blended min/avg/max across unrelated series wouldn't mean anything.

### CPU Load Graph

A scrolling 60-second graph of both core loads:

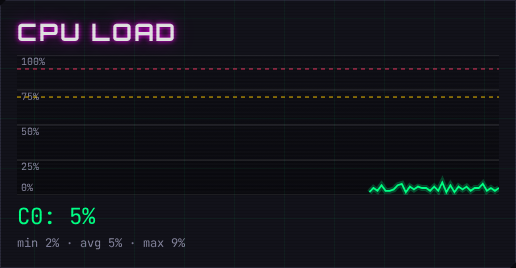
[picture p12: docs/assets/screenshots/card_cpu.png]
CPU Load graph


- **Core 0 (cyan)** — handles Wi-Fi, WebUI HTTP, Art-Net, DMX, safety, and the pattern render pipeline. Measured on a reference board at 44 kpps: ~1% with nothing rendering, ~1–2% on a preset served from the pipeline output cache, and ~15–25% on one that regenerates every frame. Sustained readings well above that are worth investigating; the render path's own share can be attributed stage by stage via [`GET /api/tasks`](08-api-reference.md#get-apitasks) → `render`.
- **Core 1 (magenta)** — sits at ~100% permanently and that is correct, not a fault. `galvoTask` busy-waits between DAC ticks to hold the sample clock steady, so the core is never idle by design.
- Warning lines at 70% (yellow dashed) and 90% (red dashed) mark potential overload on Core 0. They do not apply to Core 1.

> **Firmware older than 6.83.0 reported this wrong.** The load figure was derived from a
> baseline captured over the whole boot window, so an idle Core 0 read ~73% and the true
> 0–100% range was squeezed into roughly 73–100%. If you are comparing against numbers
> noted down from an older build, re-measure them rather than trying to convert.

### Temperature History Chart

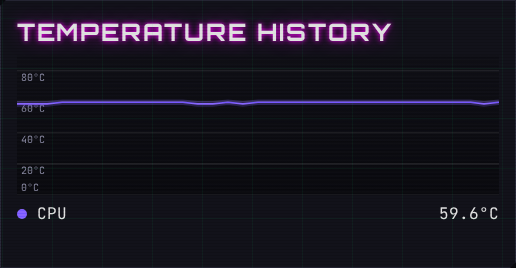
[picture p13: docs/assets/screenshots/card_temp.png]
Temperature History chart


A colour-coded scrolling chart of all DS18B20 sensor readings, plus the ESP32-S3's own internal die temperature (violet):

- 🔴 Laser diode module
- 🟠 Driver board
- 🟡 Galvo board
- 🟢 PSU
- 🔵 Ambient / chassis
- 🟣 ESP32 CPU (internal die sensor, no external probe)

Current temperatures are shown as a row of badges below the chart. Sensors that report as not connected are skipped entirely rather than drawn as a dead flatline; the CPU reading always shows since it needs no external probe. Per-sensor names, calibration offsets, and the display unit (°C/°F/K) are set on the [Thermal tab](#tab-thermal).

### Galvo Output Rate

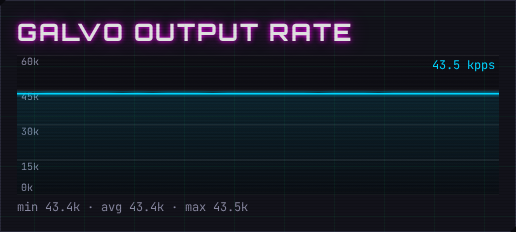
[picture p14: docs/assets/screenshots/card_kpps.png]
Galvo Output Rate chart


A scrolling 5-minute history of the actual DAC output rate in kpps (points-per-second). This is the real-time equivalent of the "Galvo Rate" bar in the Telemetry card, plotted over time so you can spot dips or instability instead of just the instantaneous value. Compare against the configured `galvo_kpps` (Tab: Projection) to confirm the output stays at the expected rate under load.

### Frame Composition Chart

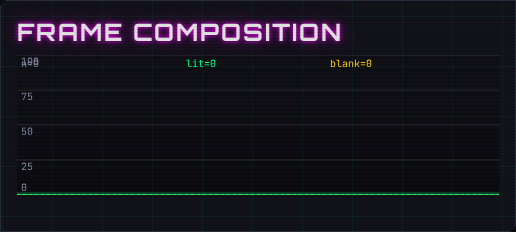
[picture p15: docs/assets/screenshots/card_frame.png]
Frame Composition chart


Shows how each rendered frame's points split between **Lit** (green) and **Blank** (orange) against the **Total** point count (grey) over the same 5-minute window. A high blank-to-lit ratio usually means the optimizer is spending a lot of the frame budget on travel/jump moves between shapes rather than visible content — useful when tuning optimizer profiles (Tab: Optimizer) or diagnosing why a complex pattern looks dim or flickery.

### Buffer Fill Chart

A scrolling history of the DAC output ring buffer's fill level (%), the same value shown live in the Telemetry card's buffer-fill readout — plotted over time so a sustained climb toward the warning (80%, yellow dashed) or critical (95%, red dashed) line is visible before it turns into an actual overflow, rather than only after flicker has already started.

### WiFi Signal (RSSI) Chart

A scrolling history of Wi-Fi signal strength in dBm, with green/yellow/red background bands instead of needing to memorize what a given dBm number means — strong (≥ −60 dBm), medium, and weak (≤ −75 dBm). Useful for correlating a controller that drops out of reach with a genuinely weak link versus some other cause (see the gateway-watchdog notes in [Troubleshooting](07-troubleshooting.md)).

### Zone Clipping Card

A one-checkbox quick toggle for projection zone clipping — the full zone editor (polygon, outline projection) stays on the [Calibration tab](#tab-calibration). Handy for flipping the safety fence on/off without leaving the Dashboard.

### System Card

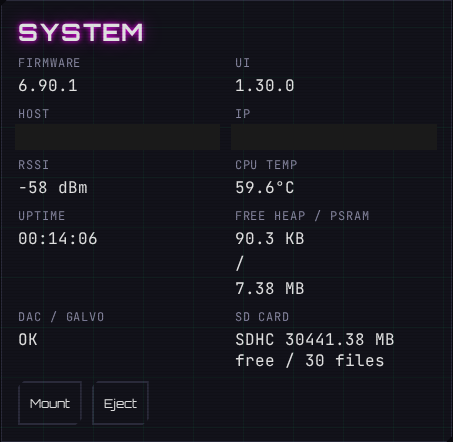
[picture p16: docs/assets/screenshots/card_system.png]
System card


System information in a compact multi-column field grid: firmware version, **UI version** (independent of firmware), hostname, IP address, Wi-Fi signal strength (RSSI), **CPU Temp** (ESP32-S3 internal die sensor), uptime, free heap (internal DRAM), free PSRAM, NTP time, and DAC/galvo status. It also carries the **SD card status plus Mount/Eject controls** — the full SD toolset lives on the [ILDA / SD tab](#tab-ilda--sd). The API auth token is on the **Access Credentials** card of the Configuration tab.

> **Note:** there is no per-interface activity LED card. Interface enable/disable and debug logging live on the Configuration tab ([Control Interfaces](#control-interfaces)); per-interface activity is reported by the API (`/api/state` → `etherdream_connected`, `osc_active`, …).

---

## Tab: Presets

The Presets tab is the **complete performance control surface** — everything you touch during a show lives here. It is laid out as a wide main column (Global Controls, Color Animations, Preset Grid, Community Presets, Sequencer) plus a right-hand sidebar (BPM Clock, Countdown Timer, Parameter Modulators, Bindings).

### Global Controls

A card that applies to every active preset in real time. Changes take effect immediately without reloading the pattern; sliders start neutral, and their travel matches the range the firmware actually acts on.

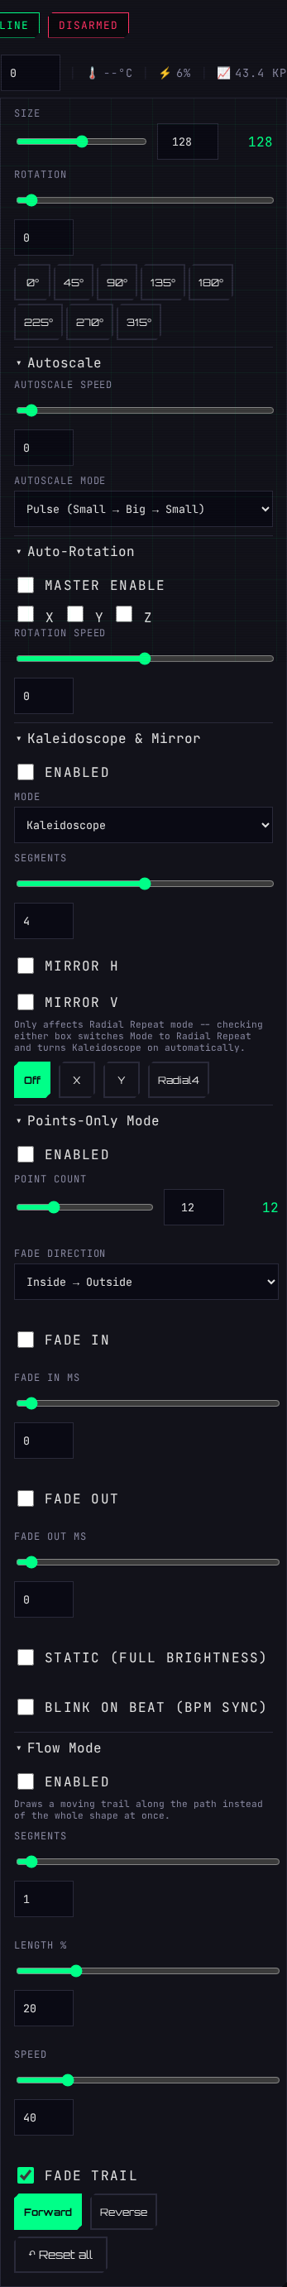
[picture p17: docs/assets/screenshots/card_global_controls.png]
Global Controls card


**Speed / Size / Autoscale / Rotation:**

- **Speed** — pattern animation speed (0–255, default 0 = static). Meaning varies by preset: step increment, phase advance, or oscillation rate.
- **Size** — scales the pattern output (0–255). 255 = full scan range. Reduce to shrink the image. For Starfield, Size instead requests a star count — the readout shows the actual rendered count (`starfield_stars` in `/api/state`), which can be lower than requested if the Particles optimizer profile's `max_pts_per_frame` budget caps it first.
- **Autoscale Speed / Mode** — oscillates size at the set rate (default 0 = off). Modes: Off, Fit, Fill.
- **Rotation** — static rotation offset (0–359°).
- **Wave Amplitude** (0.1–2.0×) / **Wave Frequency** (0.25–4.0×) — only meaningful for Waves-category presets (moved into Global Controls).
- Some presets reveal **extra parameter rows** when active (e.g. Fireworks: Trail/Endless/Duration; Spiral: Arms; Spiderweb: Rings/Sides; Starburst: Rays; Matrix Rain: Dots/Tilt).

**Auto-Rotation:**

- **Master enable** plus per-axis **X / Y / Z** checkboxes — pick which axes spin.
- **Rotation Speed** — one shared speed slider for all enabled axes, −0.5 to +0.5. The value is radians added per pattern frame, so it is deliberately small: 0.3 already means more than a full revolution per second.

**Kaleidoscope & Mirror:**

- **Mode** — **Kaleidoscope** (default) is a true dihedral mirror-fold: the source is folded into one wedge and stamped around it with alternating rotation/reflection, so adjacent segments mirror each other across their shared edge like a real optical kaleidoscope. **Radial Repeat** is the older plain rotational copy — the same wedge stamped around N times with no fold, optionally alternating Mirror H/Mirror V per segment (those two checkboxes only apply in this mode and are disabled under Kaleidoscope, which builds its own symmetry).
- **Segments** — 2/4/6, even only (the dihedral fold requires an even count to close exactly; default 4).
- **Mirror** — simpler reflection, independent of the above: Off, X (horizontal flip), Y (vertical flip), Radial4 (4-fold copy without reflection).

**Color:**

- **Color wheel** — click or drag to select hue and saturation (properly round again, even on narrow screens), with a brightness slider next to it.
- **Hex input** — type a hex color code directly (`#ffc96e` etc.).
- **Quick color buttons** — one-tap access to R, G, B, Magenta, Yellow, Cyan, White.

**Points-Only Mode:**
Converts any preset into a dot-cloud: instead of drawing connected lines, the optimizer samples points from the pattern and dwells on each one as a lit dot.

- **Enabled** — on/off.
- **Point Count** — number of dots (2–50, default 12; `POINTS_MODE_MAX_DOTS` in `config.h` is the matching firmware ceiling).
- **Fade In / Fade Out** — enable smooth brightness ramp at each dot, with configurable duration (0–5000 ms).
- **Fade Direction** — controls the order in which points fade: Inside→Outside, Outside→Inside, Left→Right, Right→Left, Top→Bottom, Bottom→Top.
- **Static Mode** — disables fading entirely; all dots at full brightness.
- The **Dotter** module can scatter these dots via a modulator binding on the `DOT_SPREAD` target — see [Parameter Modulators & Bindings](#parameter-modulators--bindings-sidebar).

**Flow Mode:**
Instead of drawing the whole geometry at once, lights only a moving window (or several) of the path — a flowing line/trail traveling along whatever the preset drew. Unlike Points-Only Mode it never re-samples or reorders points; it only ever blanks more of them, so the beam keeps tracing the preset's exact point spacing and blank-jump structure — no new galvo jump is ever introduced.

- **Enabled** — on/off.
- **Segments** — number of simultaneous trails, evenly spaced along the path (1–8).
- **Length %** — trail length as a percentage of the lit path (1–100%).
- **Speed** — 0–255, mapped internally to 0.05–3.0 laps/second over the full lit path, so trail speed reads the same regardless of how many points the preset/size happen to produce.
- **Forward / Reverse** — direction of travel along the path.
- **Fade Trail** — tapers brightness from the trail's tail to its head (floored so the tail stays visible, not just the leading dot).
- Runs immediately before Points-Only Mode in the render pipeline — enabling both makes the dwell dots sample from whatever the trail currently lights, rather than the full geometry.

**↺ Reset all** — resets all Global Controls sliders to their defaults without changing the active preset.

### Color Animations

Its own full-width card directly below Global Controls. Seven animation modes applied on top of any color override, laid out as a type selector (left), the active mode's panel (middle — color sequence grid or swatches), and speed/direction/actions (right):

- **Gradient** — smooth color cycle through a selected sequence. Choose a sequence (0–9) and set direction and speed.
- **Chase** — one color at a time, cycling through a sequence.
- **Strobe** — rapid on/off at the set speed in the selected color.
- **Pulse** — sine-wave brightness oscillation in the selected color.
- **Twinkle** — random brightness spikes; simulates a glitter/spark effect.
- **Color Flip** — hard cuts between R, G, B, W at the set speed.
- **Segment** — divides the pattern's points into segments, each painted a different color from the selected palette. Segment count and direction are adjustable.
- **⏹ Stop Animation** — stops any running color animation and returns to the last static color.
- **↺ Reset Colors** — clears any color override and returns to the preset's built-in color. Use this if colors appear washed out after a color animation.

The speed slider defaults to 1, the lowest visible speed. Note that speed 0 does **not** mean "paused": the animation phase always advances by a small fixed floor, so a near-zero setting reads as "slow", not "stuck".

### Preset Grid

The main preset library, fetched from `/api/presets` on tab load. Each preset is shown as a tile with an SVG thumbnail and name. Waves and 3D presets live here too — they're just categories in the same grid, not separate cards. Each tile carries a small per-category glyph that draws itself in on hover — a purely cosmetic flourish, but a satisfying one.

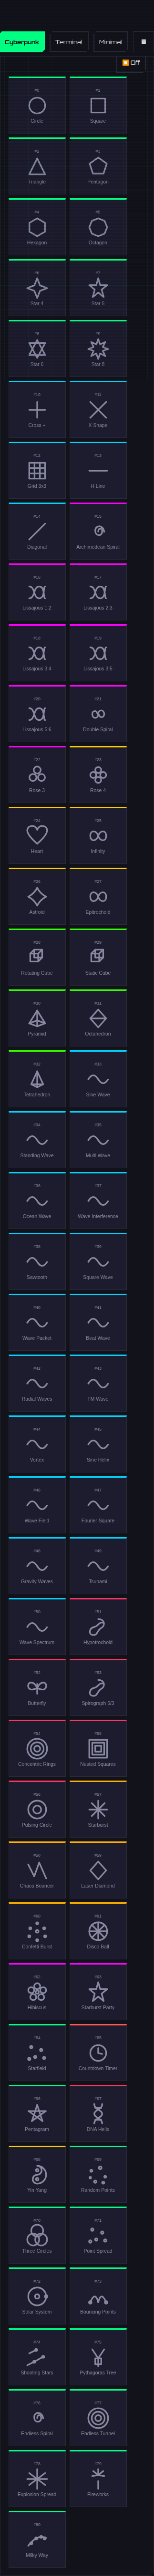
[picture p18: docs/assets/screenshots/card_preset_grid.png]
Preset Grid card


- **Category filters** — buttons above the grid filter by category (Geometry, Waves, 3D, Scenes, etc.). Click to toggle. Multiple categories can be active simultaneously.
- **Click a preset** — activates it immediately. The active preset name is shown in the Global Controls header.
- **⏹ Off** — stops the current preset (laser off).
- **↺ Reset all** — resets all Global Controls sliders to their defaults without changing the active preset.
- Waves presets pick up their **Amplitude** / **Frequency ×** from Global Controls Column 1. 3D presets use the **Auto-Rotation** controls in Column 2 for movement — rotation is not built into each preset, enable Auto-Rotation in Global Controls to spin them.

### Community Presets

A full-width card directly below the Preset Grid, showing every community preset stored on the device, each tile marked with a **COMMUNITY** badge.

- **Click a tile** — activates the preset: applies its playback params (built-in preset, color, speed, size) and layers its optimizer tuning on top of the live optimizer config. The active preset name shows as "Name (Community)".
- **＋ Browse / Manage** — jumps to the Preset Manager tab.
- If nothing is stored yet, the card tells you to go browse in the Preset Manager tab. It's not wrong.

### Sequencer

A BPM-synced preset playlist, directly below Community Presets. Build a list of steps (preset + duration in beats + optional transition), and the sequencer walks them in time with the [BPM Clock](#bpm-clock-sidebar):

- **Step editor** — each step has a preset, a duration (1/2/4/8/16/32 beats), an optional **transition** (beats of blanked output before the next step — the beam goes dark, but colors/rotation/modulators keep animating underneath, so nothing freezes), and an enable checkbox.
- **Transport** — status pill, a beat-flash dot, and Prev / Start / Stop / Next buttons. Start jumps to step 0; Prev/Next are hard cuts that ignore beat timing.
- **Loop** — repeat the playlist indefinitely, or stop after the last step.
- The playlist persists on the device — but playback **never auto-starts on boot**, by design. A Class 4 laser that resumes its show when the power comes back is nobody's idea of a feature.

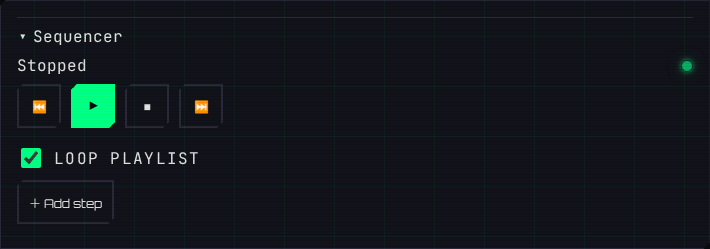
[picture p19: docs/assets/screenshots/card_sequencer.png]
Sequencer card


### BPM Clock (sidebar)

The global tempo everything beat-synced (Sequencer, Modulators) runs on. Three sources with fixed priority **DMX > Tap > Manual**:

- **Manual** — type a BPM (20–300).
- **TAP** — a big, satisfying tap-tempo button; tap along at least twice and the clock follows (resets after a 3 s pause).
- **DMX** — a configurable absolute DMX channel (default 237) drives the tempo, mapped 1:1 (channel value *v* = *v* BPM, no rescale). Set the channel under Configuration → DMX BPM Source. Only active while a DMX/Art-Net signal is actually present. Channel value **0 is Beat-Stop**: the beat phase freezes where it is (the source stays DMX, it does not fall through to Tap/Manual) and resumes from the same fractional position when the value goes back above 0.

The source pill shows which input currently owns the clock.

### Countdown Timer (sidebar)

Set hours/minutes/seconds, then Start/Pause/Stop. On expiry: do nothing, show a text message (Text mode), or play an ILDA file.

### Parameter Modulators & Bindings (sidebar)

The animation engine that makes patterns *move on their own*. Up to **8 modulator slots**, each generating a continuous control signal, routed to live pattern parameters through up to **16 bindings**. The sidebar cards are collapsible and reorderable, and modulator slots follow an add-on-demand pattern: only slots in use are rendered, with an **+ Add Modulator** button revealing the next free one.

**Modulator types:**

- **Oscillator** — Sine, Triangle, Square, or Saw wave. Triangle/Square gain a Slope/Shape control (square duty cycle, saw↔triangle↔ramp morph).
- **Noise** — smooth random wander, with a persisted seed so a slot's curve survives reboots instead of reinventing itself.
- **Envelope** — externally triggered ramp. Either the classic Attack/Sustain/Release, or a multi-point breakpoint curve: up to 8 points, 6 curve types, One-Shot/Loop/Ping-Pong/Trigger modes.
- **Step Sequencer** — up to 16 hand-set values stepped through in time.

Each slot is BPM-synced (whole note down to sixteenth) or free-running in Hz, with level, phase offset, and a name.

**Bindings** route a modulator onto a target parameter with **depth** and **offset**. Built-in targets: transform scale X/Y, shift X/Y, rotation, color hue/saturation/brightness, animation speed, and point density. Self-registering firmware modules add more (the dropdown picks them up automatically from the device):

- **Camera** — yaw/pitch/roll/dolly/FOV on the five 3D wireframe presets (Cube, Pyramid, Octahedron, Tetrahedron & Co.), including an optional perspective divide. All neutral by default — nothing moves until you bind something.
- **Duplicator** — clone the frame N times in a grid, radial, or spiral arrangement, with per-copy offset/angle/scale.
- **Spatial Noise** — a 2D value-noise modulator *type* for organic, hand-drawn-looking wobble.
- **Dotter** — scatter Points-Only-Mode dots (`DOT_SPREAD`), deterministic per dot so the cloud breathes instead of shimmering.

Modulators act on Preset-mode rendering; Text/Paint/ILDA output is not modulated. Slider changes apply instantly but are written to flash lazily (400 ms idle debounce), so dragging a depth slider does not fire a flash write per tick.

---

## Tab: Preset Manager

Home of the Community Presets feature: preset bundles hosted in the GalvOS GitHub repo, downloadable straight from the WebUI. Each bundle is a single JSON that carries a full optimizer tuning (same fields as the Optimizer tab) plus playback params (which built-in preset to run, color, speed, size) — someone else's 2 AM slider-tweaking session, packaged for your device.

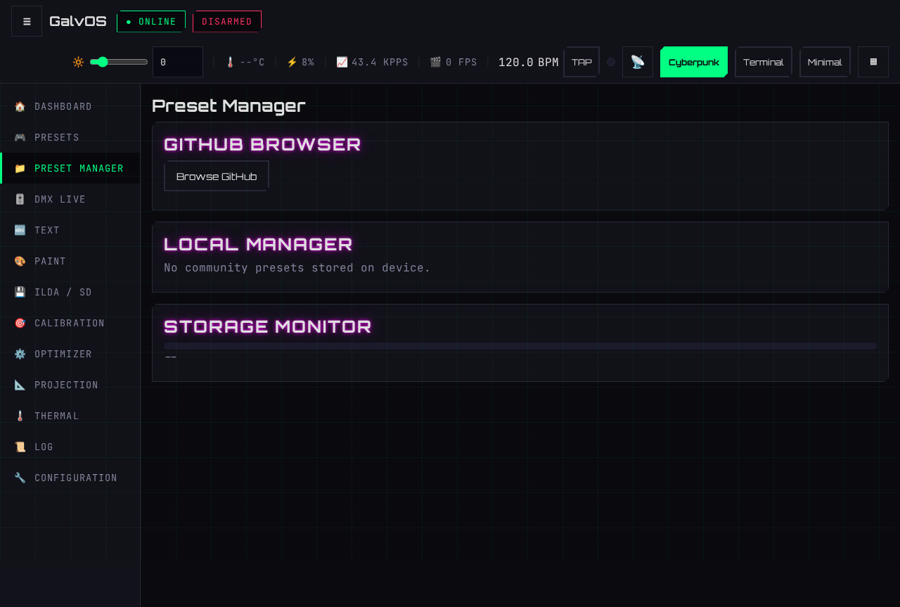
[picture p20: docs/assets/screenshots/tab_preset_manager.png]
Preset Manager tab


### GitHub Browser

- **⟳ Browse GitHub** — fetches the community preset index from `raw.githubusercontent.com` and shows each entry as a card with name, author, description, and tags. Your **browser** does the fetching — the firmware never talks to GitHub itself, so this works even though the ESP32 has no internet-facing ambitions.
- **Download** — the browser downloads the preset JSON and POSTs it to the device, where it is validated against the schema and written to LittleFS. It then appears under Presets → Community Presets and in the Local Manager below.

> **Note:** Browsing requires the device you're viewing the WebUI on (phone/desktop) to have internet access. The ESP32 itself does not need any.

### Local Manager

A table of every community preset stored on the device (Name, Author, Size):

- **✎ Rename** — edits the display name in place (Enter or ✓ to confirm). The id and filename stay unchanged.
- **🗑** — deletes a single preset (with confirmation).
- **Checkboxes + 🗑 Delete selected** — bulk delete.
- **⟳ Refresh** — reloads the list from the device.

### Storage Monitor

A usage bar showing LittleFS storage: preset count and used/total space. Each preset is capped at 10 KB and the device stores at most **20 community presets** (updating an existing one doesn't count against the limit), so filling this up would take genuine dedication.

> **Note:** Activating a community preset applies its optimizer tuning as a session-only override — it is not persisted. Selecting another preset or rebooting returns to the built-in optimizer profile for that preset class.

Want to publish your own? See [Contributing a Community Preset](09-contributing.md#contributing-a-community-preset).

---

## Tab: DMX Live

Provides a software DMX console — 25 sliders corresponding to GalvOS's 25 DMX channels.

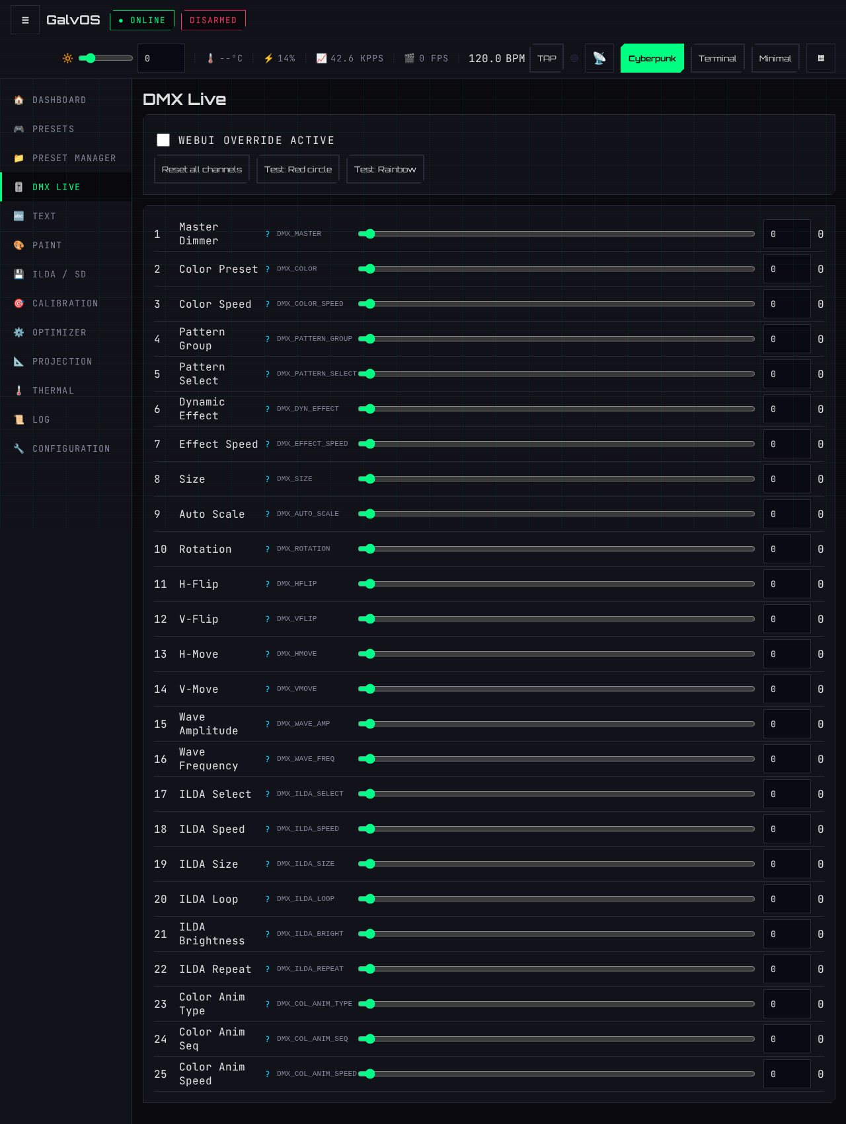
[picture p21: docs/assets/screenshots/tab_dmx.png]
DMX Live tab


- **WebUI override toggle** — when enabled, the slider values are sent directly to the pattern engine, overriding any incoming hardware DMX signal. When disabled, the sliders display the last received DMX values (read-only view).
- **Reset all channels** — returns all sliders to their off/default state.
- **Test: Red circle** / **Test: Rainbow** — quick preset buttons that set a combination of channels to show a test pattern.

Full channel map: see [Chapter 3 — Build & Configuration → RuntimeConfig → DMX/Art-Net](03-build-and-config.md).

---

## Tab: Text

Projects laser text. Text mode overrides any active preset and DMX input while active.

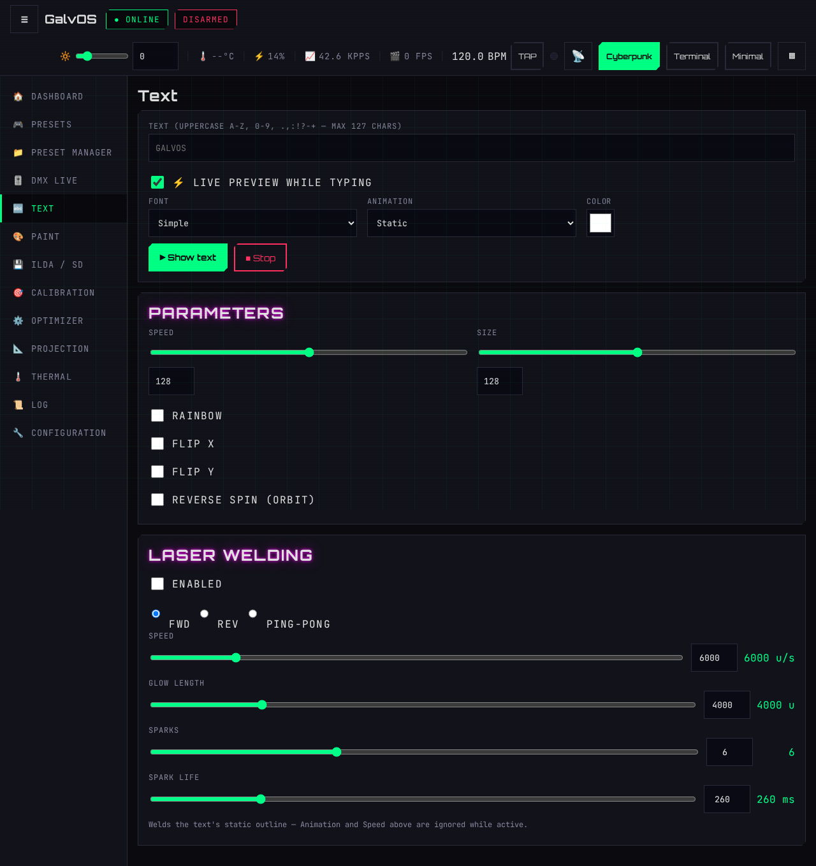
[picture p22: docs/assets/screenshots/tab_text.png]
Text tab


- **Text input** — supports uppercase A–Z, digits 0–9, and `.,:!?-+`. Maximum 127 characters. Up to 16 characters display statically; longer text scrolls automatically.
- **Font** — Simple (thin strokes, fastest), Bold (thick strokes), Outline (double-line).
- **Animation** — Static, Scroll Left/Right, Bounce, Typewriter, Wave, Pulse, Rotate, Zoom, Orbit, Star Wars Scroll.
- **Live toggle** — when on, text updates are sent to the laser as you type. Turn off if you want to compose text before displaying it.
- **Speed / Size** — animation speed and text size.
- **Color / Rainbow** — fixed color via color picker, or rainbow cycling across characters.
- **Flip X / Flip Y** — mirror the text output horizontally or vertically.
- **🔄 Reverse Spin (Orbit)** — flips the Orbit animation's rotation direction; has no effect on other animations.
- **▶ Show text / ⏹ Stop** — activate or deactivate text mode. Leaving the text field empty and pressing Show falls back to `GALVOS`.

---

## Tab: Paint

A freehand drawing canvas that projects directly onto the laser.

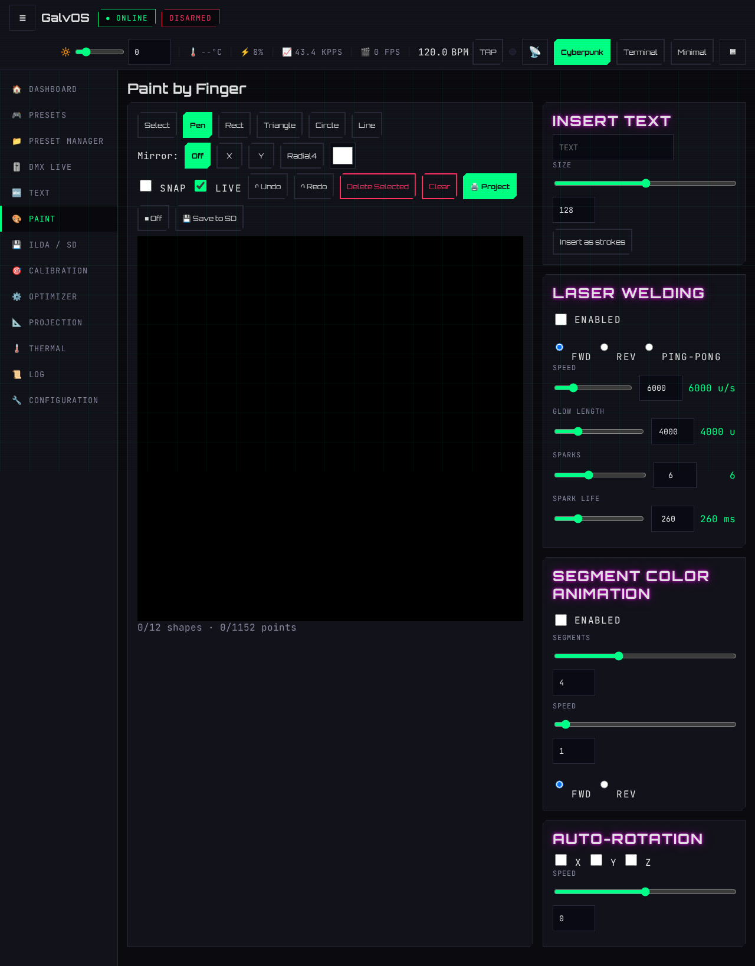
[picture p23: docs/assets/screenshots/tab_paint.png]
Paint tab


### Paint by Finger

- **Tools** — Select, Pen (freehand), Rect, Triangle, Circle, Line. Shapes are stored as closed polygons, exactly like a drawn stroke.
- **Mirror** — Off / X / Y / Radial4: mirrors the stroke as you draw it.
- **Snap** — snaps new points to a grid, for shapes that are meant to look deliberate.
- **Live** — pushes every edit to the laser as you make it, instead of waiting for Project.
- **↶ Undo / ↷ Redo / Delete Selected / Clear** — the usual editing set; Clear empties the canvas.
- **Color picker** — sets the color for the next stroke.
- **🖨 Project / ■ Off** — activates or deactivates Paint mode. Paint output overrides the active preset and DMX input.
- **Counter** — a live `n/12 shapes · m/1152 points` readout, so you can see the budget filling up before it bites.

The canvas is scaled to match your configured **projection zone** (fetched from `/api/zone` on load, falling back to the ±24000 default range if no zone is enabled), with the zone outline drawn as a dashed guide — so strokes drawn near the canvas edge don't get clipped by zone blanking. **Limits:** 12 strokes, 96 vertices per stroke.

### Insert Text

Renders a short text at a chosen **Size** into the canvas as ordinary strokes ("Insert as strokes"). Once inserted, the glyphs are just shapes: selectable, movable, and deletable like anything else you drew. This is independent of the [Text tab](#tab-text), which is its own output mode.

### Laser Welding

An alternative renderer of the same canvas: a bright torch head travels the drawn path, trailing a fading afterglow and throwing ballistic sparks. Active only while Paint mode is on and this card is **Enabled**.

- **Direction** — Fwd / Rev / Ping-Pong.
- **Speed** — head travel in path units per second (default 6000). Wall-clock driven, so travel speed does not change with the frame rate.
- **Glow Length** — afterglow trail length in path units (default 4000).
- **Sparks** / **Spark Life** — spark count (4–10) and lifetime in milliseconds.

Welding settings are live-only — they are not persisted to NVS.

### Segment Color Animation

Splits the canvas path into **Segments** and cycles colors along them at the set **Speed**, forward or reverse. A cheap way to make a static drawing move without touching the geometry.

### Auto-Rotation

Per-axis **X / Y / Z** checkboxes plus a shared **Speed** slider, applied to the whole canvas — the same control idea as the Presets tab's Auto-Rotation, scoped to Paint output.

---

## Tab: ILDA / SD

ILDA file playback from an SD card. This tab is the single home for everything SD/ILDA: the file browser, the player, the show playlist, uploads, and the SVG import/library.

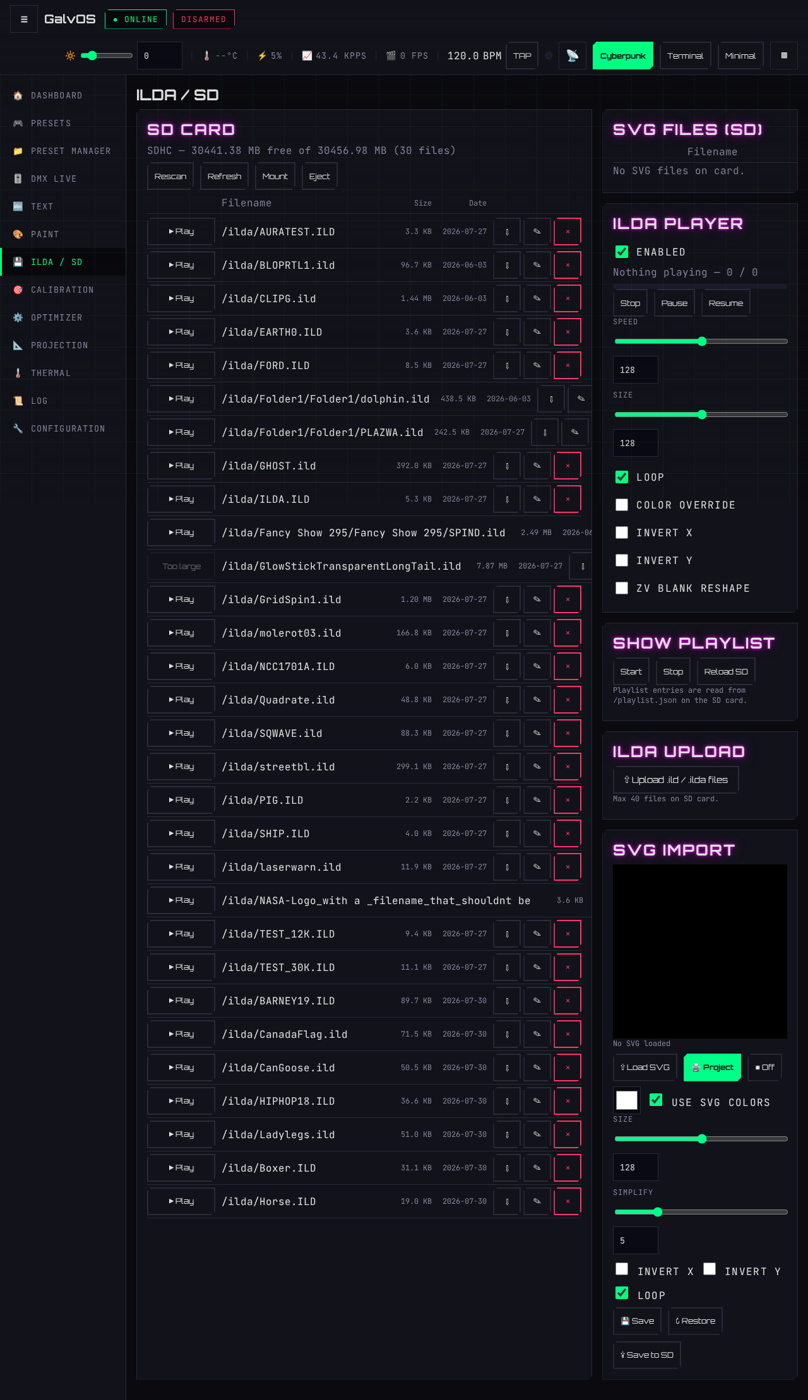
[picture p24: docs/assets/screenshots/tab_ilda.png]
ILDA / SD tab


### SD Card

- **File list** — lists `.ild` files found on the SD card (up to 40 files), including **subfolders** (folder prefixes are highlighted so `Fancy Show 295/opener.ild` reads at a glance) with per-file size and date. Each entry has a ▶ Play button; while a big file loads, the row shows a **Loading… → Done** indicator instead of playing dead.
- **Per-file actions** — ⬇ download a file back to your browser, ✎ rename it, or 🗑 delete it (with confirmation), all straight from the row.
- **Oversized files are grayed out** — the firmware estimates the worst-case PSRAM cost per file before you play it and disables Play for files that would blow the budget, with the reason on hover. Better a gray row than a watchdog reset mid-show.
- **Rescan / Refresh / Mount / Eject** — full SD control right in the tab. The card **auto-mounts on a standing 5-second retry**, so a card inserted at any time gets picked up; there is no one-shot mount window at boot to catch. An intentional Eject disables the watcher (so the card isn't re-mounted behind your back) until you press Mount again.

### ILDA Player

- **Enabled** — master switch; disabling force-stops playback and ignores both WebUI and DMX file-select until re-enabled.
- **Now playing + progress bar** — file name and frame progress, live.
- **Speed / Size** — apply live to the running file via `/api/ilda/param`, on the next frame, without reloading it.
- **Loop / Color Override / Invert X / Invert Y** — loop mode, a live color picker override, and per-axis mirroring.
- **Stop / Pause / Resume** — transport controls.
- ILDA frames get only a light optimizer touch: the live affine transform (your position/size/rotation) and a velocity clamp so a wild point jump baked into someone else's `.ild` can't blindside a low `galvo_kpps` setting. Resample, corner dwell, and blanking stay hands-off — the file's author already made those calls.

### Show Playlist

Sequential playback of multiple ILDA files: Start/Stop controls; entries are read from `/playlist.json` on the SD card, with per-entry loop count and pause duration (see [Chapter 8 — Playlist](08-api-reference.md#playlist)).

### ILDA Upload

Upload `.ild`/`.ilda` files to the SD card straight from the browser. Filenames are sanitized and length-capped server-side — long names survive up to FAT's real 255-character limit, and hostile ones can't traverse directories or corrupt the index.

### SVG Import

Converts an SVG drawing into a Paint canvas — entirely in the browser, no firmware-side SVG parsing. The result projects through the same pipeline as the Paint tab's freehand shapes (`/api/paint/set`), so it inherits that budget:

| Limit | Value | Matches |
| --- | --- | --- |
| Strokes (paths) | 12 | `PAINT_STROKES_MAX` |
| Vertices per stroke | 96 | `PAINT_VERTS_PER_STROKE` |
| Total points | 1152 (12×96) | stays under the 1300 optimizer frame budget |
| Raw samples per path (pre-simplify) | 400 | — |

**Pipeline:** `Load SVG` reads the file, walks the DOM (`<g>` recursed, `<defs>`/`<symbol>`/`<clipPath>`/etc. skipped), rewrites `rect`/`circle`/`ellipse`/`line`/`polyline`/`polygon` to equivalent `path` data, samples each path at 400 points via `getPointAtLength` + `getCTM` (so nested `transform`s resolve correctly), then simplifies with Ramer-Douglas-Peucker (`epsilon = Simplify / 1000`). Paths are then prioritized longest-first into the 12 stroke slots — a path that still doesn't fit one 96-vertex slot after simplification is dropped whole, never truncated mid-path.

**Controls:**

- **Preview canvas** — black background, redraws live on every slider change (Simplify/Size/Invert/color), without re-parsing the SVG.
- **Status line** — `N paths · M pts` when everything fit; `N/T paths · M pts · D dropped` in amber otherwise.
- **Load SVG** — local file picker. **Project** — pushes the current result to the Paint canvas and activates Paint mode. **Off** — deactivates Paint mode (keeps the canvas).
- **Color picker + "Use SVG colors"** — per-path color resolves from `stroke` (preferred) or `fill`, walking the CSS cascade via `getComputedStyle`; falls back to the picker color when a path has neither (or the checkbox is off).
- **Size** (0–255, 128 = 100%) — scales around the drawing's center. **Simplify** (1–20) — RDP tolerance. **Invert X / Invert Y** — per-axis mirroring (SVG's Y axis is inverted against galvo Y by default, before this toggle). **Loop** — display-only preference (Paint mode loops inherently); saved/restored but never sent to the firmware.
- **Save / Restore** — round-trips the full card state (including the raw SVG text) through `localStorage` (`galvos_svg_state`), same pattern as the theme picker.
- **Save to SD** — uploads the currently loaded SVG text to the card (see below).

**SD storage:** the "SVG Files (SD)" card lists `.svg` files under `/svg/` with the same layout as the ILDA file list. Files that fail a pre-check (too large, malformed — no `<svg>` root, or no drawable elements found) show a disabled "Blocked" button with the reason on hover, exactly like ILDA's oversized-file graying. Pressing Play fetches the raw text and runs it through the same import pipeline as a local "Load SVG".

---

## Tab: Calibration

The calibration workflow covers six areas: galvo geometry, color/gamma parameters, the projection zone, geometric warp, brightness compensation, and the ILDA standard test pattern.

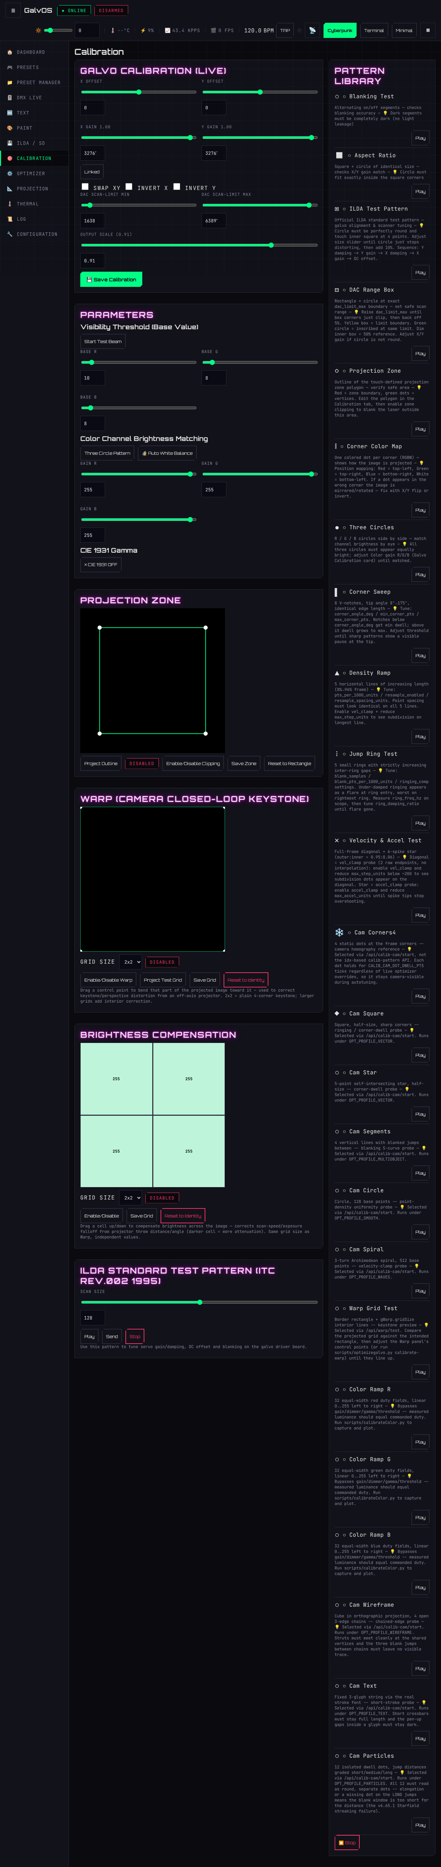
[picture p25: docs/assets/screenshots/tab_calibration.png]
Calibration tab


### Pattern Library

A list of calibration patterns to project while adjusting parameters. Select a pattern to activate it; press ⏹ Stop to return to normal operation. Pattern descriptions:

| Pattern | Purpose |
| --- | --- |
| White fill | Full-white output — for overall brightness assessment |
| Red / Green / Blue fill | Single-channel output — for per-channel threshold calibration |
| Three Circles | One solid R, G, B circle side by side — for white balance matching |
| Crosshair | Geometric reference for offset and gain calibration |
| Grid | Linearity check across the full scan range |
| DAC Range Box | Corner-to-corner rectangle at full DAC range — for DAC limit calibration |
| ILDA Test Pattern | Official ILDA 1995 test pattern — for galvo driver tuning |

### Galvo Calibration (live)

Live geometry adjustments, sent to the hardware on every slider change:

- **X/Y Offset** — center the output image. Adjust until the crosshair pattern is centered on the projection surface.
- **X/Y Gain** — scale the image. The "Linked" button keeps X and Y gain equal (maintains aspect ratio).
- **Swap X/Y** — swap the X and Y galvo channels if they are wired in reverse.
- **Invert X / Invert Y** — mirror the output along either axis.
- **DAC limit min/max** — restrict the DAC output range to keep the OPA4134 output within the galvo's ±5V input rating. Default: 0x0666..0xF999.
- **Output Scale** — proportional shrink about the center, applied before the DAC limit clamp. Use it when corners clip: the clamp flattens them, this scales the whole image so they stay in the linear range instead.

Press **💾 Save calibration** to persist all values to NVS.

### Parameter Card (visibility threshold & white balance)

**Visibility threshold (base value):**

Each laser diode has a minimum PWM duty below which it emits no visible light — the dead zone. The threshold calibration finds this minimum so GalvOS can map 0–100% logical brightness onto the actually visible range.

Procedure:

1. Press **▶ Start test beam** — a static low-level beam activates on each channel, bypassing gain, gamma, and master dimmer so only the threshold sliders control it.
2. For each color channel, lower the slider until that color just goes dark. The value at which it disappears is the threshold.
3. Press **💾 Save thresholds**.

**Color channel brightness matching (White Balance):**

1. Press **▶ Start the Three Circle Pattern** — three solid circles (R, G, B) appear side by side.
2. Adjust Gain R / G / B until all three circles appear equally bright to the eye.
3. Alternatively, press **🪄 Auto White Balance** — the firmware calculates gains from the configured laser power values and applies them automatically.
4. Press **💾 Save calibration**.

**CIE 1931 Gamma:**
Toggles perceptual brightness correction. When enabled (default), the firmware applies a γ≈2.2 transfer curve so equal numerical steps in brightness look equal to human perception. Disable only if you need linear 0–255 output for a specific application.

### Projection Zone

An interactive canvas for defining a clipping polygon — the area the laser is allowed to scan. Lit points outside the polygon are blanked (laser off, mirror position retained).

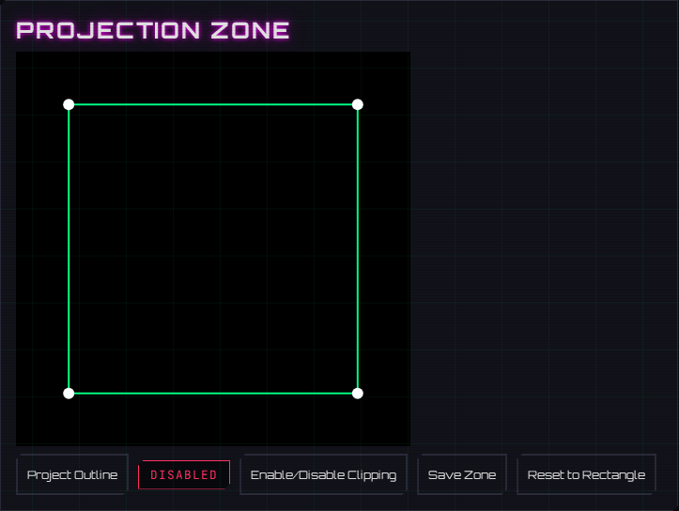
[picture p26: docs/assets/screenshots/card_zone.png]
Projection Zone card


- **Drag vertices** to shape the zone.
- **Tap an edge** to add a new vertex.
- **Double-tap a vertex** to remove it (minimum 3 vertices).
- **Project Outline** — projects the zone boundary onto the screen so you can verify it matches your safe scan area.
- **⬛ Enable Clipping** — activates zone clipping. Only enable after verifying the outline is correct.
- **Save Zone / Reset to Rectangle** — save or discard changes.

### Warp (Camera Closed-Loop Keystone)

A grid editor for geometric correction of an off-axis projector. Drag a control point to bend that part of the image toward it.

- **Grid Size** — 2×2, 3×3, 4×4, or 5×5 control points. 2×2 is plain four-corner keystone; larger grids add interior correction for a non-flat surface.
- **Project Test Grid** — projects the grid itself so you can see what you are correcting against.
- **Enable / Disable Warp**, **Save Grid**, **Reset to Identity**.

Warp is applied inside the optimizer pipeline, after geometry generation, so it corrects everything the projector draws — presets, text, paint, and ILDA files alike. With the grid at identity, the stage is skipped entirely.

### Brightness Compensation

The same grid editor aimed at photons instead of geometry: drag a cell to attenuate that part of the image. Scan speed — and therefore exposure per unit path length — varies with throw distance and angle, so a geometrically correct image can still be visibly brighter in the middle than at the edges.

- **Grid Size** — same 2×2 … 5×5 options as Warp, with independent values.
- **Enable / Disable**, **Save Grid**, **Reset to Identity** (identity = 255, no attenuation).

It scales the emitted RGB only — it never writes back into a pattern's own colors, and it is not the same thing as a color override.

### ILDA Standard Test Pattern (ITC Rev.002 1995)

The official ILDA test pattern with a **Scan Size** control, for tuning servo gain/damping, DC offset, and blanking on the galvo driver board. **Play** projects it, **Send** pushes a size change to the running pattern, **Stop** ends it.

### Camera-in-the-Loop Auto-Tuning (calib-cam)

There is a second calibration path that doesn't live in this tab at all: the `/api/calib-cam/*` REST API, driven by a companion host-side Python tool (`scripts/optimizeGalvo/optimizeGalvo.py`) using a mono/global-shutter USB camera. It projects dedicated reference patterns, measures them with the camera, and runs an automated Optuna search over optimizer scan/dwell parameters — the manual "tune a slider, look at the beam, repeat" loop, done in software instead.

This does **not** replace the Galvo Calibration card above (offset/gain/swap/invert are still manual) — it auto-tunes the *optimizer* profiles (Vector, Smooth, Waves, MultiObject) against camera-measured beam quality. See [Chapter 6 — Camera-in-the-Loop Auto-Tuning](06-camera-autotuning.md) for the full setup and workflow.

---

## Tab: Optimizer

Per-preset-class optimizer profile management. See [Chapter 5 — The Optimizer](05-optimizer.md) for a full explanation of what each parameter does.

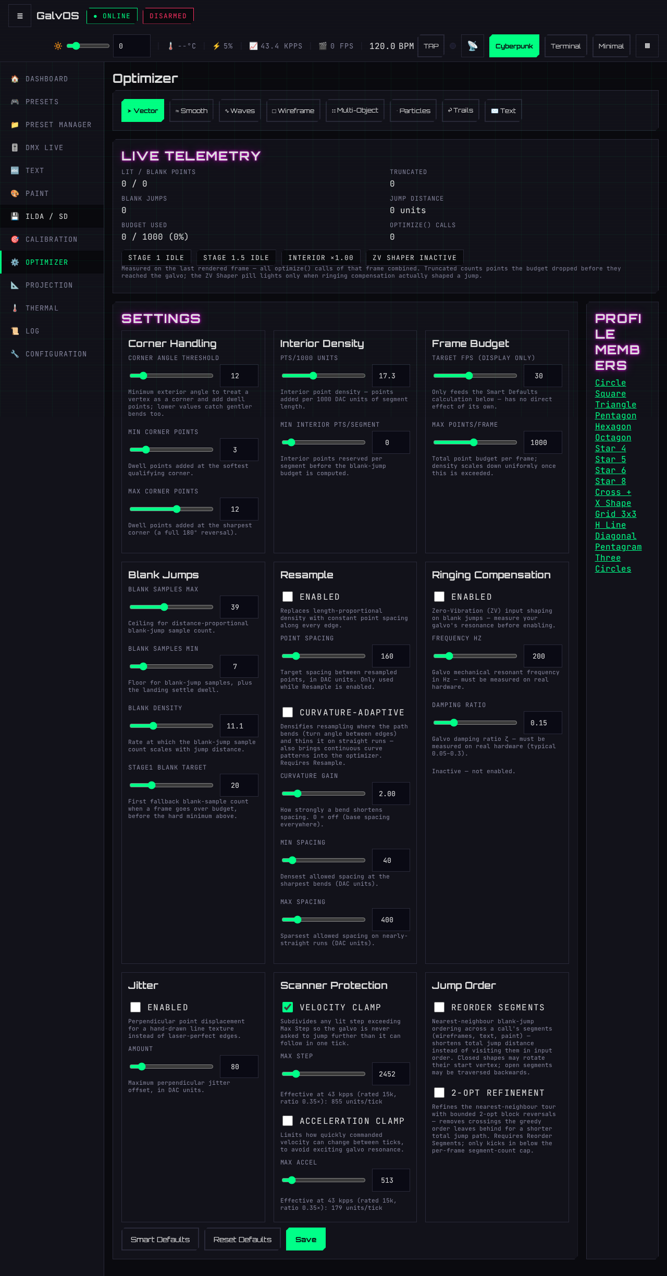
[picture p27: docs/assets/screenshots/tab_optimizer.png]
Optimizer tab


### Profile Selector

Eight optimizer profiles, one per preset class:

| Profile | Preset class | Scanner workload |
| --- | --- | --- |
| Vector | Closed polygons, straight runs | Corner dwell |
| Smooth | Continuous closed curves | Interior density |
| Waves | Open polylines, high frequency | Velocity clamp |
| Wireframe | 3D edge chains | Corner dwell + short jumps |
| MultiObject | Several closed objects | Long blank jumps |
| Particles | Isolated dots | Blank jumps only |
| Trails | Fading/decaying trails | Interior density at a reduced frame budget |
| Text | Glyph strokes | Many short open segments |

The active profile switches automatically when a preset is activated. You can also select a profile manually to edit it. The **Profile Members** card on the right lists which presets belong to the selected profile.

### Live Telemetry

Measured on the last rendered frame, combining every `optimize()` call of that frame:

- **Lit / Blank Points**, **Blank Jumps**, **Jump Distance**, **Budget Used**, and **optimize() Calls**.
- **Truncated** — points the frame budget dropped before they reached the galvo. Anything above zero here means the pattern does not fit the budget and is being cut off, not just thinned.
- **Stage pills** — Stage 1 / Stage 1.5 / Interior ×N show which budget-reduction stages fired and how far interior density was scaled back. The **ZV Shaper** pill lights only when ringing compensation actually shaped a jump (it stays dark if the impulse delay is longer than any jump in the frame, which is the normal case at low resonance frequencies).

### Smart Defaults Button

**⚙ Smart defaults** — computes recommended parameter values from `opt_max_pts_per_frame` and `galvo_kpps` and applies them to the current profile. A good starting point after changing galvo hardware or kpps setting.

### Parameter Sliders

All sliders update the active profile live and show their **effective values** (`opt_eff_*`) after PPS scaling. The effective values are what the optimizer actually uses — they may differ from the raw slider values when `galvo_kpps` differs from `galvo_rated_kpps`.

The sliders are grouped by what they do:

| Group | Contents |
| --- | --- |
| **Corner Handling** | Corner angle threshold, min/max corner points |
| **Interior Density** | Points per 1000 units, minimum interior points per segment |
| **Frame Budget** | Target FPS (feeds Smart Defaults only), max points per frame |
| **Blank Jumps** | Blank samples min/max, blank density, Stage 1 blank target |
| **Resample** | Constant-spacing resample, plus **Curvature-Adaptive** mode with curvature gain and min/max spacing |
| **Ringing Compensation** | ZV input shaping on blank jumps: enable, resonant frequency, damping ratio, and a status line reporting whether shaping actually engages at the current settings |
| **Jitter** | Deterministic perpendicular displacement of interior points, for a hand-drawn line texture instead of laser-perfect edges |
| **Scanner Protection** | Velocity clamp (max step) and acceleration clamp (max accel) |
| **Jump Order** | **Reorder Segments** (nearest-neighbour jump ordering) and **2-opt Refinement** (removes crossings the greedy tour leaves behind; requires Reorder Segments) |

Every field is persisted, included in backups, and honored by community presets.

**Smart Defaults** recomputes the group above from the frame budget and sample rate; **Reset Defaults** restores the compile-time profile defaults; **Save** writes the profile to NVS.

See [Chapter 5 — The Optimizer → Parameter Reference](05-optimizer.md#parameter-reference) for a full table of all parameters.

---

## Tab: Projection

Hardware configuration for the galvo scanner and laser module.

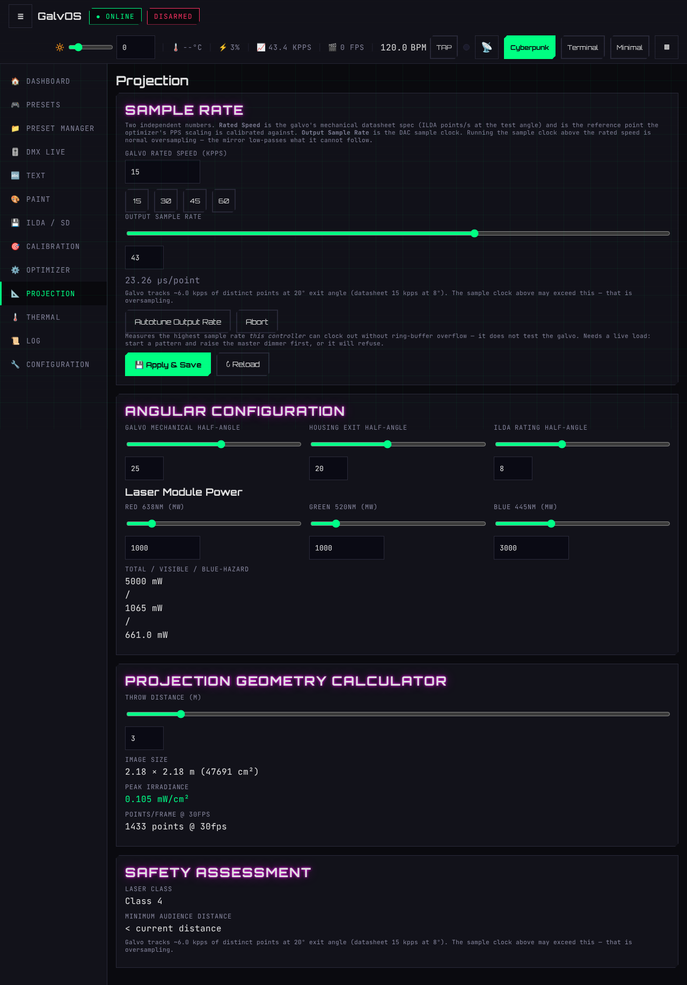
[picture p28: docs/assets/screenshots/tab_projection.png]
Projection tab


### Galvo Sample Rate Card

- **Galvo rated speed** — set this to your galvo's datasheet kpps rating (Jolooyo JY-15K-BL = 15 kpps). This is the PPS-scaling reference the optimizer's parameters are tuned against ([Chapter 5 — PPS Scaling](05-optimizer.md#pps-scaling)) — a **mechanical** point-rate figure, distinct from the DAC sample clock below.
- **Output Sample Rate slider** — `galvo_kpps`: the actual ISR tick rate (12–60 kpps, defaults its range to at least 60 regardless of rated speed, since running well above the mechanical rating is normal oversampling, not a fault). **This is the most important hardware parameter.** Start at your galvo's rated speed and only increase if the hardware handles it without distortion — use [`GET /api/state`'s `points_per_sec` against `/api/projection`'s `kpps`](08-api-reference.md#get-apistate) to confirm the board is actually delivering the commanded rate, since it silently stops keeping up well before ring-buffer overflow would tell you.
- **Autotune** — binary search for the highest kpps this specific board can sustain without falling short of the commanded rate. Start a real pattern (`master_dimmer` > 0) before running this — an idle/blanked output can't overflow at any rate and would make every trial pass regardless of the true ceiling.
- **Period readout** — shows the calculated µs per DAC sample at the current rate.
- **💾 Apply & Save** — writes kpps and rated_kpps to NVS.

### Angular Configuration Card

Physical angles of the galvo and housing setup — used for the projection geometry calculator and safety assessment:

- **Mechanical Half-Angle** — galvo mirror maximum deflection (±°).
- **Housing Exit Half-Angle** — actual beam exit limit (typically smaller than galvo limit). The Sample Rate card shows an informational line below it stating how many distinct points the mirror can mechanically track at this exit angle, derated from the datasheet figure — the DAC sample clock exceeding that number is normal oversampling, not a problem to fix.
- **ILDA Rating Half-Angle** — standard ±8°; only change if your galvo's datasheet specifies a different rating angle.

### Laser Module Power Card

Laser power in mW per channel. Used for white balance auto-calculation and the safety assessment display. Totals shown:

- **Total power** (all channels)
- **Visible power V(λ)** — weighted by eye sensitivity
- **Blue-light hazard B(λ)** — the blue channel (445 nm) has the highest photochemical retinal risk

### Projection Geometry Card

Enter throw distance (0.5–30 m) to calculate projected image dimensions, area, peak irradiance, and points-per-frame budget at 30 fps.

### Safety Assessment Card

A simplified laser hazard summary based on configured power and angles: laser class, total/visible/BLH power, estimated minimum audience distance, NE555 scan-fail status, and rate-vs-angle adequacy.

---

## Tab: Thermal

Fan and temperature management.

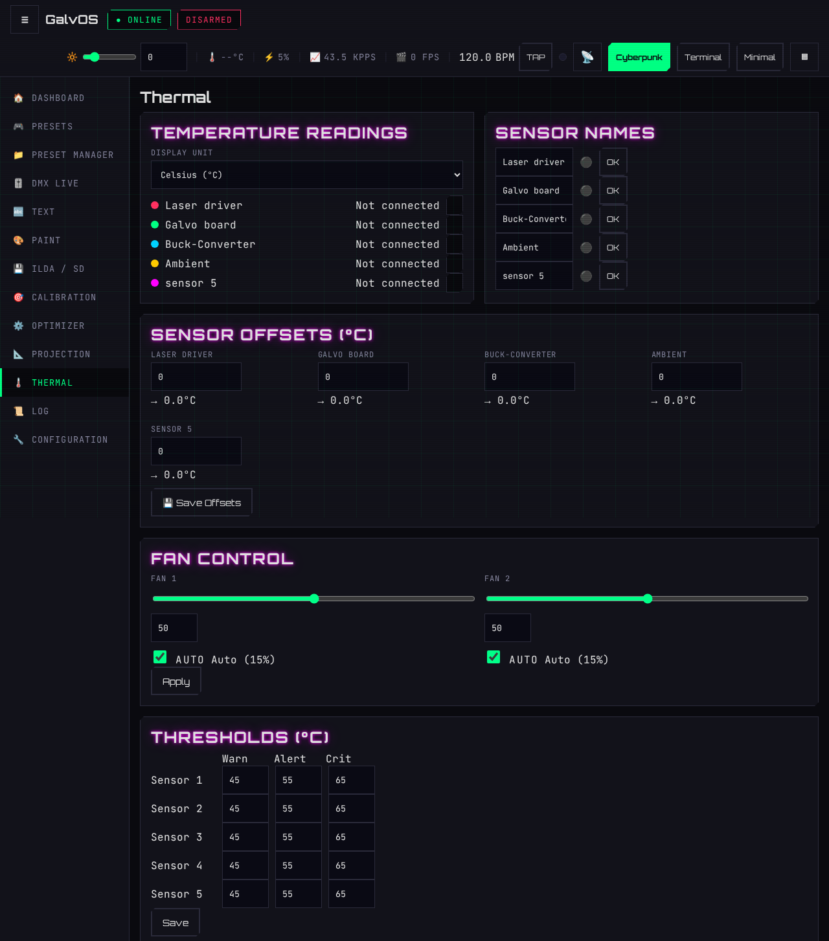
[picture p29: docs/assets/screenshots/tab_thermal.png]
Thermal tab


- **Temperature Readings** — all connected DS18B20 sensors, with a **Display Unit** selector (Celsius / Fahrenheit / Kelvin). The unit is a WebUI display preference, persisted on the device; the API and the firmware always work in °C.
- **Sensor Names** — rename each sensor so the Dashboard chart and the badges say "Laser diodes" rather than a bus index.
- **Sensor Offsets (°C)** — per-sensor calibration offset added to the raw reading, for a probe that reads consistently high or low. **💾 Save Offsets** persists them.
- **Fan Control** — Auto mode (temperature-driven) or a manual PWM override per fan. **Minimum fan speed** prevents stalling at low PWM (`fan_min_pct`, default 15%).
- **Thresholds (°C)** — warn, reduce, and shutdown temperatures (`temp_warn_c`, `temp_reduce_c`, `temp_shutdown_c`).

Current readings are also plotted on the Dashboard temperature chart.

---

## Tab: Log

Live firmware log output, streamed from the ESP32 over the WebSocket. Auto-refreshes only when this tab is active.

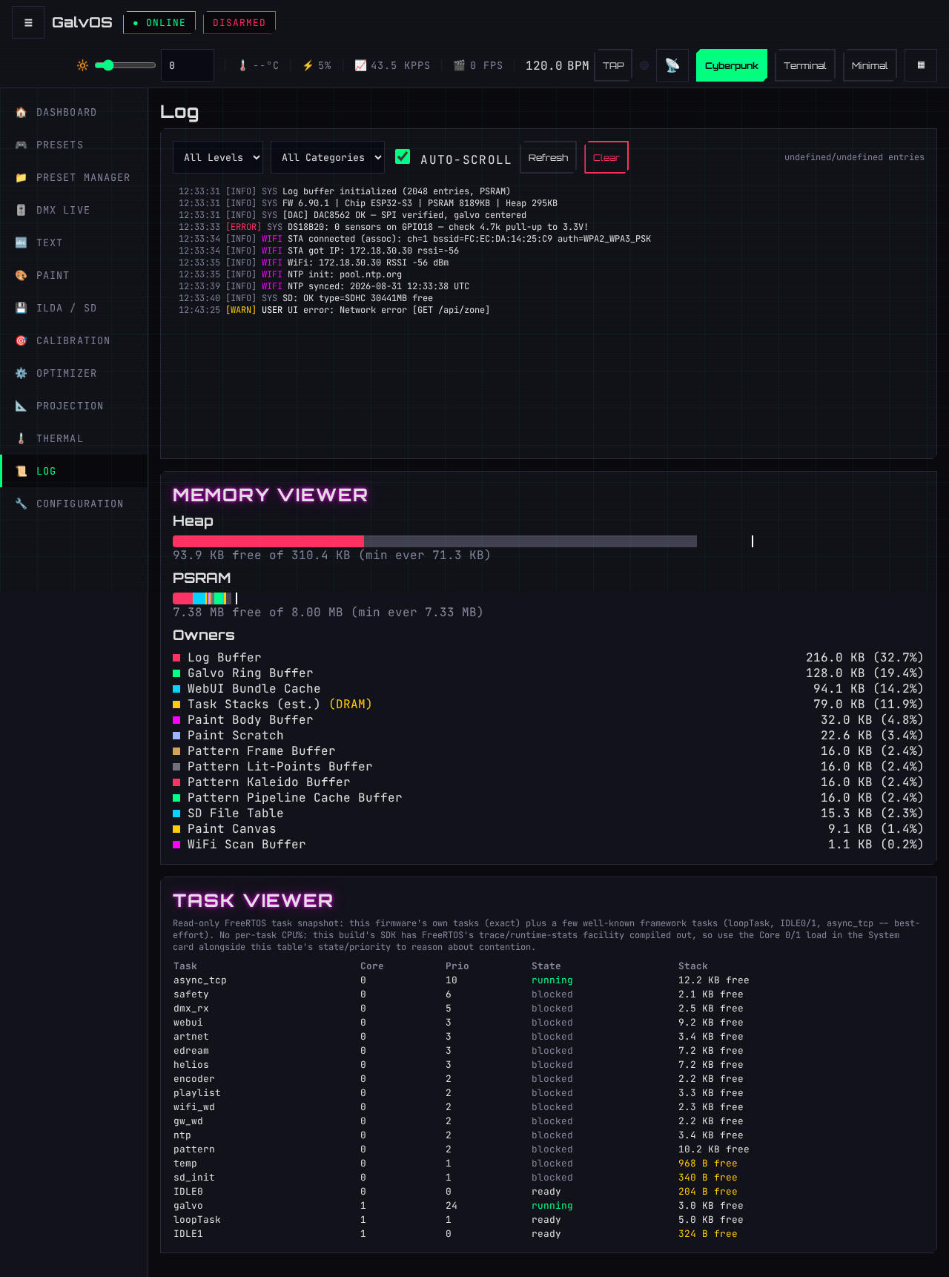
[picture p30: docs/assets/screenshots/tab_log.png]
Log tab


- Log entries are color-coded by severity: INFO (dim), WARN (orange), ERROR (red).
- Use this tab to diagnose startup issues, track DMX frame counts, or watch for ring buffer overflow warnings.
- The log buffer is limited in size — older entries are overwritten.

### Memory Viewer

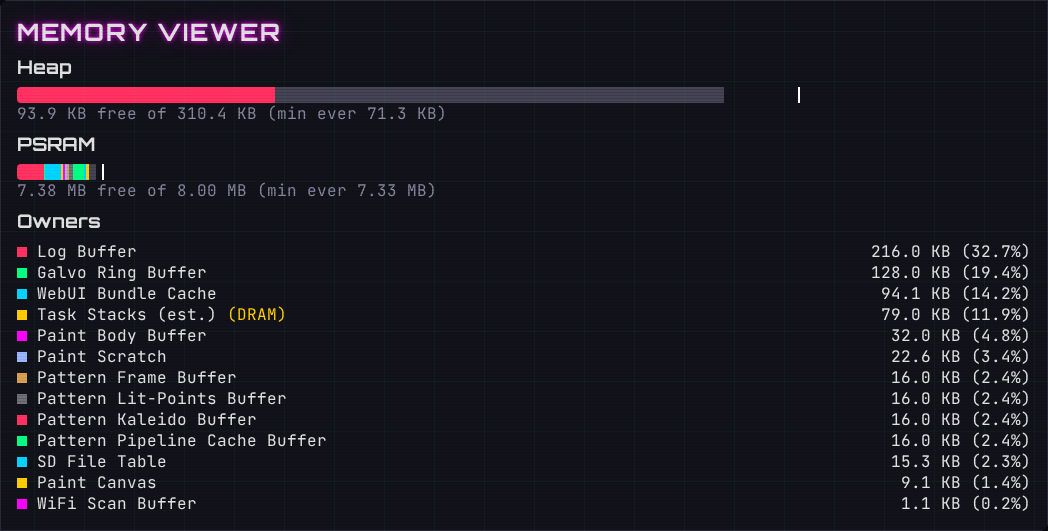
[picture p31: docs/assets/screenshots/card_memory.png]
Memory Viewer card


A second card below the log console, showing who holds the RAM — static/long-lived buffers only, sourced from `/api/meminfo` and refreshed every 3 s while the Log tab is open.

- **Internal SRAM (Heap)** — composition bar plus total, free now, largest free block, and lowest free ever since boot (the value the failsafe reboot threshold is compared against), and the failsafe reboot limit itself.
- **PSRAM** — composition bar plus total, free now, largest free block, and lowest free ever since boot.
- **Tracked Owners** — per-subsystem breakdown of registered static/long-lived allocations (see `mem_registry.h`), so a slow leak or an oversized buffer can be attributed to a specific module.
- **🔄 Refresh** — manual refresh outside the 3 s auto-cycle.

### Task Viewer

A third card below the Memory Viewer, listing the FreeRTOS tasks — which core each one
is pinned to, its priority, whether it is running, ready or blocked, and how much of its
stack has never been used. Sourced from [`/api/tasks`](08-api-reference.md#get-apitasks)
and refreshed every 3 s while the Log tab is open. It answers "what is actually running
on Core 0" without opening a serial monitor.

- **Free stack** is the high-water mark: the smallest headroom that task has ever had
  since boot, not its current depth. A task sitting in the low hundreds of bytes is
  close to a stack-canary crash and should get more.
- **State** is a single instant, not an average. Seeing a task "ready" rather than
  "blocked" usually just means it woke up while the snapshot was being taken.
- The list is deliberately incomplete: every task GalvOS itself creates is exact, a few
  framework tasks (`loopTask`, `IDLE0`, `IDLE1`, `async_tcp`) are best-effort, and
  Wi-Fi/lwIP's internal tasks cannot be enumerated at all on this build. There is no
  per-task CPU% for the same reason — see the API reference for why.

---

## Tab: Configuration

Network, DMX, safety, IP, and debug settings.

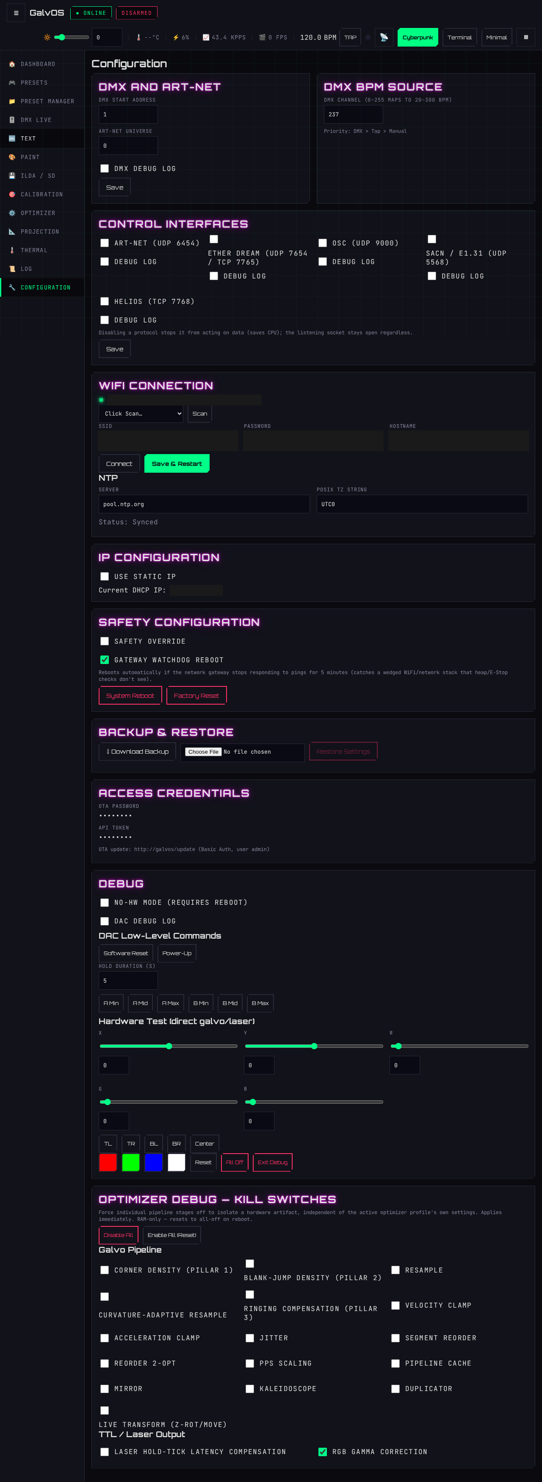
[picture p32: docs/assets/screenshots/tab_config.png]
Configuration tab


### DMX and Art-Net

- **DMX Start Address** (1–512) — first DMX channel GalvOS responds to.
- **Art-Net Universe** (0–32767) — Art-Net universe number.
- **DMX Debug Log** — logs incoming DMX traffic to Serial and the Log tab (off by default).

### DMX BPM Source

The absolute DMX channel (default 237) that drives the [BPM Clock](#bpm-clock-sidebar)'s DMX source, independent of the fixture's own start address. The mapping is 1:1 — channel value *v* means *v* BPM — and value 0 freezes the beat (Beat-Stop).

### Control Interfaces

Per-interface enable/disable, one checkbox per network input:

- **Art-Net** (UDP 6454)
- **Ether Dream** (UDP 7654 / TCP 7765)
- **OSC** (UDP 9000) — Open Sound Control 1.0 receiver, `/galvos/*` address space (see [Chapter 8 — Network Control Protocols](08-api-reference.md#network-control-protocols-non-http)).
- **sACN / E1.31** (UDP 5568, universe 1) — streaming-DMX over multicast.
- **Helios network DAC** (TCP 7768) — Helios DAC network emulation for laser software that speaks its point-stream framing.

Disabling an interface makes it ignore received data (reduces CPU load); its listening socket stays open until the next reboot. Each interface also has its own **Debug Log** toggle that writes protocol-level traffic to Serial and the Log tab — Ether Dream's is the most talkative, down to raw command bytes, for diagnosing client software that connects and then sulks. Press **Save** to persist.

### WiFi Connection

- Scan for available networks or enter SSID manually.
- Enter password. Hostname (default `galvOS`) sets the mDNS name.
- **NTP Server / Time zone** — time synchronization settings. Use POSIX TZ string format.
- **Connect** — connects without restarting. **Save & Restart** — saves and reboots.

### IP Configuration

- Toggle between DHCP and static IP.
- Enter static IP, gateway, subnet mask, and DNS when static mode is enabled.

### Safety Configuration

- **Safety Override** — bypasses E-Stop and scan-fail checks. Only use with the laser disarmed and no audience. Red warning state clearly shown.
- **⟳ System Reboot** — restarts the ESP32 immediately (confirmation prompt). Use after a config or firmware change that requires a reboot, without needing physical access to the device.
- **⚠ Factory Reset** — clears the main NVS namespace and restarts. Wi-Fi credentials are lost, so the device comes back on its own AP. See [Chapter 3 — Resetting to Defaults](03-build-and-config.md#resetting-to-defaults) for what it does *not* clear.

### Backup & Restore

Because "I remember my DAC limits" is not a disaster recovery plan.

- **⬇ Download Backup** — downloads a JSON snapshot of galvo calibration, all 8 optimizer profiles, network settings, and system/thermal thresholds. The filename carries the firmware version and a timestamp (`galvos_backup_v<fw>_<yyyy-mm-dd-hh-mm-ss>.json`), so a folder full of backups tells you which is which.
- **⬆ Choose Backup File** — pick a previously downloaded backup. GalvOS does a quick JSON-syntax check in the browser, then enables the **⚠ Restore Settings** button (dimmed until a valid file is picked).
- **⚠ Restore Settings** — asks for confirmation, then uploads the file. The firmware validates every single value against the same bounds the live config endpoints enforce before touching anything — if even one field is out of range, the whole restore is rejected and nothing is applied. On success it persists the config and reboots automatically.
- Restore is blocked while the laser is **armed** — disarm first.
- Not a substitute for the calibration workflow — it restores *previous* known-good values, it doesn't calibrate for you. See [Tab: Calibration](#tab-calibration) if you're setting up a projector for the first time.

### Access Credentials

- **HTTP-OTA Pass** — password for the `/update` OTA endpoint (user `admin`). Masked; hover to reveal. See [Chapter 3 — Wireless / OTA Update](03-build-and-config.md#wireless--ota-update) for the full walkthrough.
- **API Token** — current `X-Auth` token required for write access to the HTTP API. Masked; hover to reveal, click to copy. (Moved here from the Dashboard System Card.)

### Debug

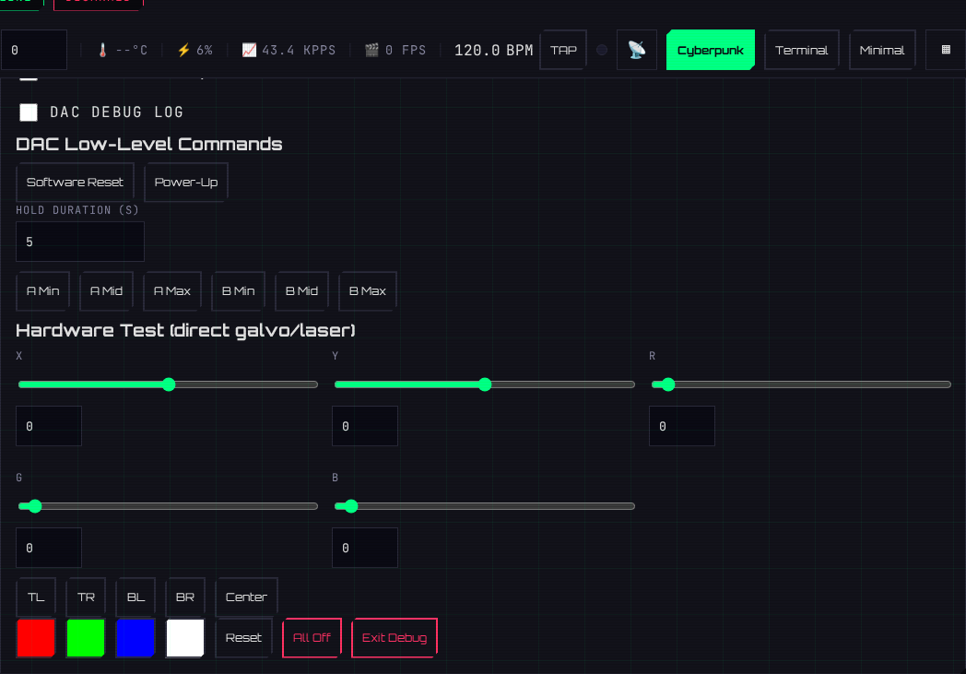
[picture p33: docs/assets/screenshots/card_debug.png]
Debug card


- **No-HW Mode** — skips SPI/DAC init at boot. Use only for firmware development without hardware connected. Disable before normal operation.
- **DAC Debug Log** — logs DAC8562 register writes to serial and the Log tab (rate-limited). For low-level DAC debugging only.
- **DAC Low-Level Commands** — sends raw DAC8562 commands (Software Reset, Power-Up) and drives either channel to its min/mid/max code for a configurable hold duration. This bypasses the pattern engine entirely — it is a hardware bring-up tool, not a performance control.
- **Hardware Test (direct galvo/laser)** — positions the beam directly: X/Y sliders, R/G/B channel toggles, corner/center jump buttons, **Reset**, **All Off**, and **Exit Debug**. While active it blocks normal pattern output.
- **Status** — the current preset and a tail of the log, so you can see what the device thinks it is doing without switching tabs.
- **OTA Update** — firmware update via HTTP at `http://laser/update` (admin / your password). The page itself covers firmware and WebUI updates, a config backup shortcut, and a reboot button — see [Chapter 3 — Wireless / OTA Update](03-build-and-config.md#wireless--ota-update).

### Optimizer Debug — Kill Switches

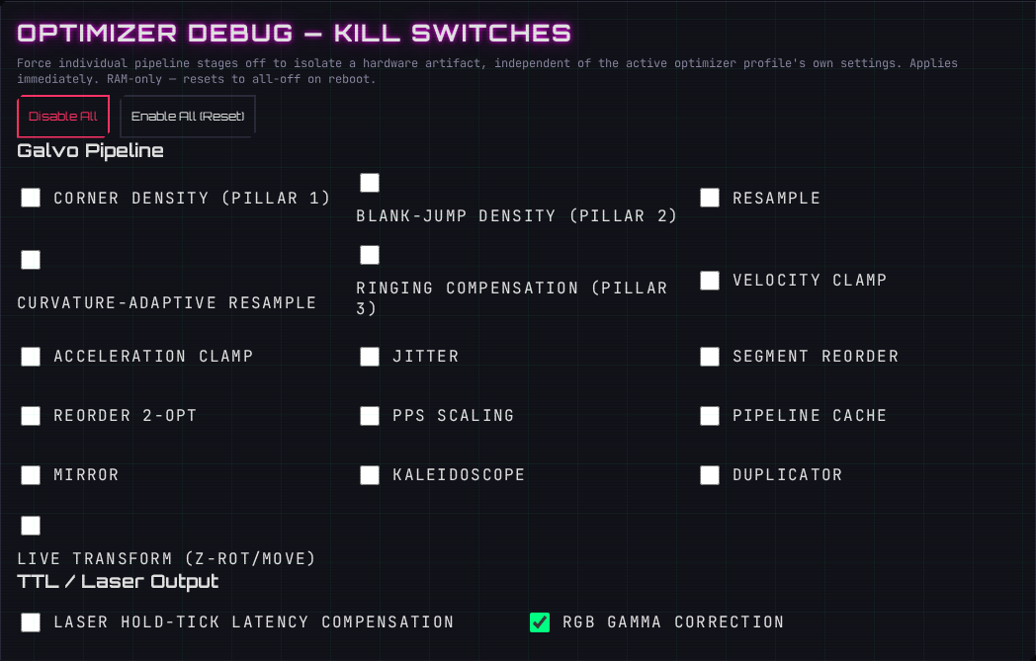
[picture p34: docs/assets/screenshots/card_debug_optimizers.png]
Optimizer Debug — Kill Switches card


A separate card directly below Debug, backed by [`GET`/`POST /api/debug/optimizers`](08-api-reference.md#get-apidebugoptimizers). Each checkbox forces one render-pipeline stage off, independent of whichever optimizer profile is active — for isolating a hardware artifact (ringing, clipping, a stray jump) one variable at a time without touching that profile's own saved settings.

- **Galvo Pipeline** — Corner Density (Pillar 1), Blank-Jump Density (Pillar 2), Resample, Curvature-Adaptive Resample, Ringing Compensation (Pillar 3), Velocity Clamp, Acceleration Clamp, Jitter, Segment Reorder, Reorder 2-opt, PPS Scaling, Pipeline Cache, Mirror, Kaleidoscope, Duplicator, Live Transform (Z-rotation/move).
- **TTL / Laser Output** — Laser Hold-Tick Latency Compensation, RGB Gamma Correction.
- **Disable All** / **Enable All (Reset)** — flips every switch at once, e.g. to strip the pipeline down to bare geometry, or to snap back to a known-clean baseline after a debugging session.

**RAM-only — resets to all-off on reboot.** A forgotten switch can't silently haunt the next power cycle, but it also means these are a *this-session-only* tool: to compare two settings, start from an **active** profile (a static, mostly-off profile like Particles will show little to no visible difference with everything else disabled too).

---

*Next: [Chapter 5 — The Optimizer](05-optimizer.md)*

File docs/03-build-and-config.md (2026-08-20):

# Chapter 3 — Build & Configuration

*Previous: [Chapter 2 — Prerequisites](02-prerequisites.md)*

## Table of Contents

- [Repository Setup](#repository-setup)
- [PlatformIO Build](#platformio-build)
- [Flash Instructions](#flash-instructions)
- [Wireless / OTA Update](#wireless--ota-update)
- [platformio.ini — Build Parameters](#platformioini--build-parameters)
- [Partition Table](#partition-table)
- [config.h — Compile-Time Constants](#configh--compile-time-constants)
- [RuntimeConfig — User Parameters](#runtimeconfig--user-parameters)
- [ProjectionConfig — Galvo & Laser Parameters](#projectionconfig--galvo--laser-parameters)
- [SafetyConfig — Temperature Thresholds](#safetyconfig--temperature-thresholds)
- [Optimizer Defaults](#optimizer-defaults)
- [Warp, Brightness & Inverse Filter](#warp-brightness--inverse-filter)
- [pinmap.h — GPIO Assignments](#pinmaph--gpio-assignments)
- [NVS — Parameter Persistence](#nvs--parameter-persistence)
- [Resetting to Defaults](#resetting-to-defaults)

---

## Repository Setup

Clone the repository and open it in VS Code with the PlatformIO extension installed:

```bash
git clone https://github.com/Andre1Becker/GalvOS.git
cd GalvOS
code .
```

PlatformIO detects `platformio.ini` automatically. On the first build it will download the ESP32-S3 platform toolchain (~500 MB) and all library dependencies. This happens once — subsequent builds are fast.

**Library dependencies** are declared in `platformio.ini` and managed automatically. You do not need to install anything manually:

| Library | Version | Purpose |
| --- | --- | --- |
| `esp32async/AsyncTCP` | ^3.4.10 | Async TCP for ESPAsyncWebServer |
| `esp32async/ESPAsyncWebServer` | ^3.11.1 | WebUI HTTP server + WebSocket |
| `someweisguy/esp_dmx` | ^4.1.0 | DMX-512 receive via UART |
| `rstephan/ArtnetWifi` | git | Art-Net UDP receiver |
| `bblanchon/ArduinoJson` | ^7.0.4 | JSON serialization (PSRAM allocator) |
| `paulstoffregen/OneWire` | ^2.3.8 | 1-Wire bus |
| `milesburton/DallasTemperature` | ^3.11.0 | DS18B20 temperature sensor driver |
| `ArduinoOTA` | bundled | Network push updates over port 3232 |
| `SD` | bundled | FAT32 SD card access (ILDA/SVG files, playlists) |

---

## PlatformIO Build

All build actions are run from the PlatformIO VS Code sidebar or the terminal:

```bash
# Build firmware (no flash)
pio run

# Flash firmware only (data/index.html not updated)
pio run --target upload

# Flash LittleFS only (updates WebUI, firmware not changed)
pio run --target uploadfs

# *** RECOMMENDED: build and flash everything in one step ***
pio run --target upload_all

# Open serial monitor (115200 baud)
pio device monitor
```

**Important:** Any change to files in the `data/` directory (the WebUI) requires `upload_all` or `uploadfs` — a firmware-only flash will not update the WebUI. The same applies in reverse: changes to firmware source files do not require an `uploadfs`.

### What `upload_all` Does

The `scripts/upload_all.py` pre-build script adds a custom target that:

1. Builds the LittleFS image from `data/`
2. Flashes the firmware
3. Flashes the LittleFS

The `scripts/gzip_assets.py` pre-build hook automatically gzip-compresses `index.html` (and any other HTML/CSS/JS/SVG files in `data/`) before the LittleFS image is assembled. This reduces the on-flash size from ~440 KB to ~105 KB and eliminates a heap spike that occurred when serving the uncompressed file over Wi-Fi. The uncompressed originals remain in `data/` as the editable source; only the `.gz` variants are served.

---

## Flash Instructions

1. Connect the ESP32-S3 DevKitC-1 to your PC via USB (the USB port labeled "UART", not "USB").
2. On the **first flash** of a new board, or if the partition table has changed, hold the BOOT button while pressing EN, then release both. This puts the board in download mode.
3. Run `pio run --target upload_all`.
4. After flashing, the ESP32 restarts automatically.

**Serial port selection:** PlatformIO usually detects the correct port automatically. If you have multiple serial devices, set `upload_port` in `platformio.ini`:

```ini
upload_port = /dev/ttyUSB0   ; Linux
upload_port = COM5            ; Windows
```

**Upload speed:** Set to 921600 baud in `platformio.ini`. This is stable on most systems. If you see flash errors, reduce to `460800`.

---

## Wireless / OTA Update

Once a board has its first USB flash, every later update can go over Wi-Fi instead — no cable, no PlatformIO upload, just a browser. GalvOS exposes this at `http://<hostname>.local/update` (or the device's IP), protected by HTTP Basic Auth: user `admin`, password = the first 8 hex digits of the chip's MAC address (also shown as **HTTP-OTA Pass** on the Configuration tab — see [Access Credentials](04-ui-guide.md#access-credentials)).

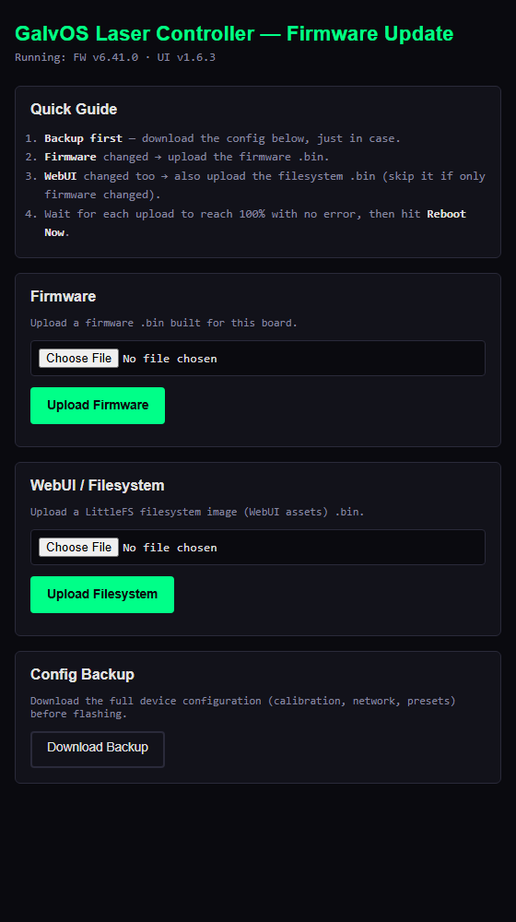
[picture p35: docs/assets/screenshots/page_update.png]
Firmware Update page


The page has three parts:

| Card | Writes to | Use it when… |
| --- | --- | --- |
| **Firmware** | whichever of `app0`/`app1` isn't currently running (see [Partition Table](#partition-table)) | anything under `src/` or `include/` changed |
| **WebUI / Filesystem** | the `spiffs` partition (formatted LittleFS, holds `data/`) | anything under `data/` (`index.html`, assets) changed |
| **Config Backup** | *(download only)* | always — before flashing anything |

Firmware and filesystem updates are independent uploads — a firmware-only change only needs the Firmware card, a WebUI-only change only needs the Filesystem one. Uploading a `.bin` that doesn't fit the target partition is rejected by `Update.begin()` rather than bricking the device.

### Steps

1. Build whichever artifact(s) you need — this only builds, it does **not** flash anything over USB:

   ```bash
   pio run                    # firmware.bin -> .pio/build/esp32-s3-devkitc-1/firmware.bin
   pio run --target buildfs   # littlefs.bin -> .pio/build/esp32-s3-devkitc-1/littlefs.bin
   ```

   Both land in `.pio/build/<environment>/` — `esp32-s3-devkitc-1` for this board. The
   `/update` page doesn't care what you name the file you upload (it matches on the form
   field, not the filename), but renaming each to include the version you're about to ship
   — `firmware_x.y.z.bin` / `littlefs_x.y.z.bin` — keeps a folder of old builds sane to
   pick through later.
2. Open `http://<hostname>.local/update` and sign in (`admin` / chip-ID password).
3. Click **Download Backup** first — same JSON as the Configuration tab's [Backup & Restore](04-ui-guide.md#backup--restore) card, and cheap insurance against a bad flash.
4. Pick the matching `.bin` under **Firmware** and/or **WebUI / Filesystem** and click its Upload button. A progress bar tracks the transfer; any `Update.write()`/`Update.end()` failure is shown inline (e.g. "not enough space", a truncated upload) instead of a bare "Update failed".
5. Once every upload you started shows its success message, click **Reboot Now**.

The laser is force-disarmed the instant an upload starts, and OTA is refused outright while armed — same rule as [`POST /api/restore`](08-api-reference.md#post-apirestore). Nothing reboots automatically on success, specifically so a multi-part update (say, firmware done but the filesystem upload still in progress) can't get rebooted into half-finished.

> **Note:** `ArduinoOTA` (IDE/CLI push over port 3232, same chip-ID password) still runs in parallel with the `/update` page — use whichever is more convenient.

---

## platformio.ini — Build Parameters

These are the parameters in `platformio.ini` that you may want to adjust. Everything else should be left at its default unless you have a specific reason to change it.

### Parameters You Will Likely Touch

| Parameter | Default | Description |
| --- | --- | --- |
| `LASER_FW_VERSION` | *(current release)* | Version string shown in the WebUI header and serial log. Increment this when you modify the firmware (see [Version Bumps](#version-bumps)). The WebUI additionally carries its own independent `UI_VERSION` (in `data/index.html`). |
| `GALVO_SAMPLE_RATE_HZ` | `30000` | The ISR tick rate — how many DAC samples are written per second. This is **not** the same as `galvo_kpps` in the WebUI (which controls how many of those ticks contain new pattern points). Default 30,000 Hz = 30 kpps effective output at full density. |
| `DEFAULT_DMX_ADDRESS` | `1` | Default DMX start address on first boot (before any NVS config). |
| `DEFAULT_DMX_UNIVERSE` | `0` | Default Art-Net universe on first boot. |
| `upload_port` | *(auto)* | Serial port for flashing. Set explicitly if auto-detect picks the wrong port. |
| `upload_speed` | `921600` | Baud rate for flashing. Reduce to `460800` if you see flash errors. |

### Parameters You Should Not Change (and Why)

| Parameter | Value | Why Not |
| --- | --- | --- |
| `board_build.flash_size` | `16MB` | Must match the N16R8 physical flash. Wrong value = flash corruption. |
| `board_build.psram_type` | `octal` | Required for the N16R8 OPI PSRAM. Other values break PSRAM. |
| `board_build.arduino.memory_type` | `qio_opi` | Required for N16R8 octal PSRAM. Do not change. |
| `board_build.partitions` | `partitions.csv` | Custom partition table — the default ESP32-S3 table is too small for the LittleFS image. |
| `BOARD_HAS_PSRAM` | defined | Enables PSRAM in the Arduino core. Without this, `ps_malloc()` does not work. |
| `ARDUINO_USB_MODE=1` | defined | Enables native USB CDC. Required for USB serial on the S3. |
| `CONFIG_ASYNC_TCP_RUNNING_CORE=0` | defined | Pins AsyncTCP to Core 0, away from the galvo ISR on Core 1. |

### Version Bumps

Version strings follow **Major.Minor.Patch**:

- **Patch** — single bug fix, one file changed
- **Minor** — new feature or refactor touching multiple call sites
- **Major** — broad architectural change

Update `LASER_FW_VERSION` in `platformio.ini` using Python string replacement (not sed — the escaped quotes make sed fragile):

```python
# In a patch script (old -> new):
content = content.replace('-D LASER_FW_VERSION=\\"x.y.z\\"',
                          '-D LASER_FW_VERSION=\\"x.y.z+1\\"', 1)
```

Each release is tagged in Git (`vX.Y.Z`) and summarized in [`CHANGELOG.md`](../CHANGELOG.md).

---

## Partition Table

`partitions.csv` defines the flash memory layout:

| Partition | Type | Size | Purpose |
| --- | --- | --- | --- |
| `otadata` | data/ota | 8 KB | OTA update bookkeeping |
| `app0` | app/ota_0 | 5 MB | Active firmware image |
| `app1` | app/ota_1 | 5 MB | OTA update staging slot |
| `spiffs` | data/spiffs | 5 MB | LittleFS — WebUI (`index.html.gz` + assets) |
| `coredump` | data/core dump | 64 KB | Core dump on crash (for post-mortem debugging) |
| `nvs` | data/nvs | 256 KB | NVS key-value store — all runtime config |

Total: ~15.32 MB of the 16 MB flash used. The LittleFS partition is labeled `spiffs` for historical PlatformIO compatibility — it is formatted as LittleFS, not SPIFFS.

The `nvs` partition is deliberately oversized (256 KB instead of the stock 20 KB) — calibration saves started failing with `NOT_ENOUGH_SPACE` once per-profile optimizer defaults, per-channel calibration, warp/brightness grids, and the inverse-filter models had all accumulated in NVS.

> **Note:** Any change to `partitions.csv` shifts every following partition's offset. If you flash a build whose partition table differs from the one already on the device, **erase the whole flash first** (`pio run --target erase` or `esptool.py erase_flash`) — otherwise the partition table and the actual flash contents disagree, and NVS reads return garbage or fail outright.

---

## config.h — Compile-Time Constants

These constants are defined in `include/config.h` and require a firmware rebuild if changed. They are not adjustable at runtime.

### Pattern Engine Limits

| Constant | Default | Description |
| --- | --- | --- |
| `PATTERN_POINTS_MAX` | `2048` | Maximum number of `LaserPoint` entries in the pattern buffer. Increasing this uses more PSRAM. |
| `POINTS_MODE_MAX_DOTS` | `50` | UI slider ceiling for the Points-Only mode dot count. |
| `POINTS_MODE_MIN_DWELL` | `3` | Minimum dwell ticks per dot in Points-Only mode. Below this, the dot is invisible. |
| `POINTS_MODE_MAX_DWELL` | `30` | Maximum dwell ticks per dot — prevents a small number of dots from consuming the whole frame budget. |
| `RANDOM_PTS_MAX_COUNT` | `14` | UI slider ceiling for the Random Points preset "Amount" parameter. |
| `KALEIDO_SEGMENTS_MAX` | `6` | UI slider ceiling for the Kaleidoscope effect segment count (even only: 2/4/6). |

### Content Limits

| Constant | Default | Description |
| --- | --- | --- |
| `PLAYLIST_MAX_ENTRIES` | `32` | Maximum entries in an ILDA playlist. |
| `PAINT_STROKES_MAX` | `12` | Maximum strokes/shapes on the Paint canvas. |
| `PAINT_VERTS_PER_STROKE` | `96` | Maximum vertices per stroke (simplified client-side before upload). |
| `ZONE_POINTS_MAX` | `16` | Maximum vertices in the projection zone polygon. |
| `WARP_GRID_MAX` | `5` | Maximum warp / brightness-compensation grid resolution (N × N control points). |
| `WELD_SPARK_COUNT_MIN` / `_MAX` | `4` / `10` | Spark count range for the Laser Welding effect. |

The SD-card file limits live in `include/pinmap.h` rather than `config.h`:

| Constant | Default | Description |
| --- | --- | --- |
| `ILDA_MAX_FILES` | `40` | Maximum `.ild` files indexed from the SD card. |
| `SVG_MAX_FILES` | `40` | Maximum `.svg` files indexed from the SD card. |
| `SVG_MAX_FILE_BYTES` | `256 KB` | Upload/playability size cap per SVG file. |
| `SVG_MAX_UPLOAD_NAME` | `60` | Maximum sanitized upload basename (excluding `.svg`). |

---

## RuntimeConfig — User Parameters

`RuntimeConfig` (defined in `include/config.h`, stored as `gConfig`) holds all parameters that can be changed at runtime via the WebUI or REST API. They are persisted to NVS and survive reboots.

### Galvo Geometry

| Field | Default | Range | Description |
| --- | --- | --- | --- |
| `galvo_x_offset` | `0` | −32767..32767 | DC offset applied to the X galvo output (DAC units). Use to center the image horizontally. |
| `galvo_y_offset` | `0` | −32767..32767 | DC offset applied to the Y galvo output. Use to center the image vertically. |
| `galvo_x_gain` | `32767` | 0..32767 | Scaling factor for X. Full scale = 32767. Reduce to shrink the image horizontally. |
| `galvo_y_gain` | `32767` | 0..32767 | Scaling factor for Y. Reduce to shrink the image vertically. |
| `swap_xy` | `false` | bool | Swap X and Y galvo channels. Use if your galvo wiring has X and Y reversed. |
| `invert_x` | `false` | bool | Mirror the image horizontally. |
| `invert_y` | `false` | bool | Mirror the image vertically. |

### DAC Output Limiting

| Field | Default | Description |
| --- | --- | --- |
| `dac_limit_min` | `0x0666` | Minimum DAC code (clips the lower end of travel). Default ≈ 2.5% from the bottom — keeps OPA4134 output within ±5.5V. |
| `dac_limit_max` | `0xF999` | Maximum DAC code (clips the upper end of travel). Default ≈ 2.5% from the top. |
| `outputScale` | `0.91` | Proportional pre-scale of X/Y about center (`0x8000`), applied **before** the clamp. `1.0` = rely on the clamp alone. |

These limits protect the galvo driver from being fed voltages outside its rated ±5V input range. The OPA4134 has a gain of 2.2× (R2/R4 = 22 kΩ instead of the theoretical 10 kΩ), so the actual output can slightly exceed ±5V at full DAC swing. The limits compensate for this. Adjust cautiously — reducing `dac_limit_min`/increasing `dac_limit_max` expands the scan angle but may stress the galvo driver.

`outputScale` and the clamp solve the same problem differently, and both are in the chain: the clamp *flattens* anything outside the window (a corner that overshoots becomes a straight clipped edge), while `outputScale` *shrinks the whole image proportionally* so those corners land inside the linear range in the first place and keep their shape. Scale first, clamp second as the final safety net.

### Color & Brightness

| Field | Default | Range | Description |
| --- | --- | --- | --- |
| `gain_r` | `115` | 0..255 | White balance gain for the red channel. Calibrated for R=1W, 638 nm (V(λ)=0.235). |
| `gain_g` | `43` | 0..255 | White balance gain for the green channel. Calibrated for G=1W, 520 nm (V(λ)=0.710). |
| `gain_b` | `255` | 0..255 | White balance gain for the blue channel. Calibrated for B=3W, 445 nm (V(λ)=0.040). |
| `gamma_enable` | `true` | bool | Enable CIE 1931 perceptual brightness correction. When enabled, the 0–255 PWM range follows human perception rather than linear power. Strongly recommended — linear laser output looks "blown out" at mid-brightness. |
| `thresh_r` | `143` | 0..255 | Visibility threshold for red: the minimum PWM duty at which the red laser diode actually emits visible light. Below this value the beam is physically dark. Calibrated via the Calibration tab. |
| `thresh_g` | `144` | 0..255 | Same for green. |
| `thresh_b` | `169` | 0..255 | Same for blue. The blue channel typically has the highest threshold. |

**How thresholds work:** The `mapVisibleRange()` function remaps the logical 0–255 color range onto [thresh_x .. 255], so "0% brightness" in patterns always means the laser is off, and "100% brightness" always means full output — regardless of the threshold. Without calibrated thresholds, the bottom portion of the brightness range does nothing visible, making the projector appear to have lower dynamic range than it actually has.

### Network

| Field | Default | Description |
| --- | --- | --- |
| `wifi_ssid` | `""` | Wi-Fi network name. Empty (or unreachable) = fall back to AP mode after the connect timeout — see [Chapter 4 → Accessing the WebUI](04-ui-guide.md#accessing-the-webui). |
| `wifi_pass` | `""` | Wi-Fi password. |
| `hostname` | `"galvOS"` | mDNS hostname. Accessible as `http://galvOS.local` on networks with mDNS support. Auto-generated from MAC if empty. |
| `wifi_static` | `false` | Use static IP instead of DHCP. |
| `wifi_ip` / `wifi_gw` / `wifi_mask` / `wifi_dns` | `""` | Static IP configuration. Only used when `wifi_static = true`. |
| `ntp_server` | `"pool.ntp.org"` | NTP server for time synchronization. |
| `ntp_tz` | `"UTC0"` | POSIX time zone string. Example for Central European Time: `"CET-1CEST,M3.5.0,M10.5.0/3"`. |

### DMX / Art-Net

| Field | Default | Range | Description |
| --- | --- | --- | --- |
| `dmx_address` | `1` | 1..512 | DMX start channel. The fixture occupies 25 consecutive channels (CH1 = Master Dimmer); see the channel map in `config.h` or [Chapter 8](08-api-reference.md). |
| `artnet_universe` | `0` | 0..32767 | Art-Net universe number. |

The BPM-clock DMX channel is configured separately (absolute 1–512, independent of `dmx_address`) — see [Chapter 4 → DMX BPM Source](04-ui-guide.md#dmx-bpm-source).

### Safety & Diagnostics

| Field | Default | Description |
| --- | --- | --- |
| `scanfail_timeout_ms` | `50` | How long the NE555 scan-fail timer runs before declaring a fault (firmware side, for display only — the hardware NE555 has its own RC time constant). |
| `watchdog_period_ms` | `500` | Hardware watchdog heartbeat interval. Firmware pulses GPIO14 at this rate; the NE555 watchdog must be retriggered within this window or it cuts the laser rail. |
| `heap_critical_bytes` | `6144` | Minimum free internal DRAM block. If internal heap fragmentation causes the largest free block to fall below this, the firmware triggers `esp_restart()`. Calibrated to 6 KB — approximately 2× margin below the measured peak load. |
| `safety_override` | `false` | Bypass software safety checks. **Use only for development.** Never enable in production. |
| `auth_hash` | `""` | SHA-256 hex of the WebUI password. Empty = default password `"laser"`. Set via the Settings tab. |
| `dac_debug_log` | `false` | Log DAC8562 writes (hex) to serial and WebUI log, rate-limited. Useful for debugging DAC output; not for production use. |

---

## ProjectionConfig — Galvo & Laser Parameters

`ProjectionConfig` (stored as `gProjection`, NVS namespace `"projection"`) holds parameters related to the physical galvo and laser hardware.

| Field | Default | Description |
| --- | --- | --- |
| `galvo_kpps` | `20` | **The most important runtime parameter.** Output rate in kilo-points-per-second. This directly controls the ISR period and how fast the galvo mirrors move. Range: 12–60 kpps. The Jolooyo JY-15K-BL is rated at 15 kpps — running above this causes missed steps and visible distortion. Start at 15 and only increase if your specific hardware handles it. |
| `galvo_rated_kpps` | `15` | The galvo's rated speed from its datasheet. Used as the basis for PPS scaling in the optimizer — do not confuse with `galvo_kpps`. If you use a different galvo set, set this to its rated speed. |
| `scan_angle_mech_deg` | `25.0°` | Galvo mechanical half-angle (±25° = 50° full sweep). Used for display and safety zone calculations. |
| `exit_angle_deg` | `20.0°` | Housing aperture half-angle — often smaller than the mechanical limit. |
| `ilda_test_angle_deg` | `8.0°` | ILDA standard rating angle (±8° optical). Used for PPS scaling calculations. |
| `power_r_mw` | `1000.0` | Red channel laser power in mW. Used for white balance auto-calculation and laser hazard display. |
| `power_g_mw` | `1000.0` | Green channel laser power in mW. |
| `power_b_mw` | `3000.0` | Blue channel laser power in mW. The blue diode in the Mikoy 5W is 3W — be aware that 445 nm carries an elevated photochemical retinal hazard (B(λ) = 0.22). |
| `distance_m` | `3.0` | Throw distance to the projection surface in meters. Used for spot size and safety calculations in the UI. |

---

## SafetyConfig — Temperature Thresholds

`SafetyConfig` (stored as `gSafety`, in the `"laser"` NVS namespace) controls the temperature-based safety responses.

| Field | Default | Description |
| --- | --- | --- |
| `temp_warn_c` | `45°C` | Temperature at which fans switch to 100% duty. Normal operation: fans run at `fan_min_pct`. |
| `temp_reduce_c` | `55°C` | Temperature at which laser power is reduced to 50% (via `thermal_power_scale`). |
| `temp_shutdown_c` | `70°C` | Temperature at which an immediate shutdown is triggered. |
| `fan_min_pct` | `15%` | Minimum fan PWM percentage. Below ~15%, most 12V fans fail to start reliably. |
| `fan_auto` | `true` | Automatic fan speed based on temperature. If false, fans run at `fan_min_pct` always. |

---

## Optimizer Defaults

All optimizer defaults are defined as `OPT_DEFAULT_*` macros in `config.h`. These set the initial values for all eight optimizer profiles on first boot (before NVS); per-profile overrides live in `OPT_PROFILE_DEFAULTS[]` in the same header. Changing them requires a rebuild and an NVS reset to take effect (existing NVS values take priority over compile-time defaults).

For a full explanation of what each parameter does, see [Chapter 5 — The Optimizer](05-optimizer.md).

| Macro | Default | Description |
| --- | --- | --- |
| `OPT_DEFAULT_CORNER_ANGLE_DEG` | `25.0°` | Minimum angle (at a vertex) that triggers corner dwell extra points. |
| `OPT_DEFAULT_MIN_CORNER_PTS` | `2` | Minimum extra points added at a corner. |
| `OPT_DEFAULT_MAX_CORNER_PTS` | `8` | Maximum extra points added at a corner. |
| `OPT_DEFAULT_PTS_PER_1000_UNITS` | `6.0` | Interior point density — points added per 1000 DAC units of segment length. |
| `OPT_DEFAULT_BLANK_SAMPLES` | `16` | Default blank jump sample count (without distance scaling). |
| `OPT_DEFAULT_GALVO_KPPS` | `30` | Fallback output rate used only when no live `gProjection.galvo_kpps` has been applied yet. |
| `OPT_DEFAULT_MAX_PTS_PER_FRAME` | `1010` | Point budget per frame. **Known effective limit: 1300** — no optical improvement is observed above this value on the JY-15K-BL hardware. |
| `OPT_DEFAULT_MIN_BLANK_SAMPLES` | `6` | Minimum blank samples (floor for distance-scaled blanking). |
| `OPT_DEFAULT_BLANK_PTS_PER_1000_UNITS` | `8.0` | Blank sample count scales with jump distance at this rate. |
| `OPT_DEFAULT_MIN_INTERIOR_PTS_PER_SEG` | `8` | Minimum interior points for longer segments. |
| `OPT_DEFAULT_STAGE1_BLANK_TARGET` | `16` | Stage 1 blank target point count. |
| `OPT_DEFAULT_RESAMPLE_ENABLED` | `false` | Constant-spacing resample stage. Disabled by default — output is identical to pre-resample when off. |
| `OPT_DEFAULT_RESAMPLE_SPACING_UNITS` | `160.0` | Spacing between resampled points in DAC units. |
| `OPT_DEFAULT_CURVATURE_RESAMPLE_ENABLED` | `false` | Curvature-adaptive resample — spends points where the path actually bends. Requires `resample_enabled`. |
| `OPT_DEFAULT_CURVATURE_GAIN` | `2.0` | How strongly curvature shortens the local spacing. |
| `OPT_DEFAULT_MIN_SPACING_UNITS` | `40.0` | Lower bound on curvature-adapted spacing (tightest corners). |
| `OPT_DEFAULT_MAX_SPACING_UNITS` | `400.0` | Upper bound on curvature-adapted spacing (straight runs). |
| `OPT_DEFAULT_RINGING_COMP_ENABLED` | `false` | ZV input-shaping ringing compensation. **Must be measured on your hardware before enabling** — wrong values make ringing worse. |
| `OPT_DEFAULT_RING_FREQ_HZ` | `200.0` | Resonant frequency of the galvo (Hz). Measure via scope step-response capture. |
| `OPT_DEFAULT_RING_DAMPING_RATIO` | `0.15` | Damping ratio of the galvo. Measure via scope. |
| `OPT_DEFAULT_VEL_CLAMP_ENABLED` | `false` | Velocity clamp. Disabled by default — tune `max_step_units` for your hardware first. |
| `OPT_DEFAULT_MAX_STEP_UNITS` | `200.0` | Maximum per-tick position change (DAC units/sample). Long lit moves above this are subdivided. |
| `OPT_DEFAULT_ACCEL_CLAMP_ENABLED` | `false` | Acceleration clamp. Disabled by default. |
| `OPT_DEFAULT_MAX_ACCEL_UNITS` | `800.0` | Maximum per-tick change in step magnitude (DAC units/sample²). |
| `OPT_DEFAULT_JITTER_ENABLED` | `false` | Point-distribution jitter (hand-drawn line texture). Off = byte-identical output. |
| `OPT_DEFAULT_JITTER_AMOUNT_UNITS` | `80.0` | Maximum perpendicular displacement of interior points, in DAC units. |
| `OPT_DEFAULT_REORDER_SEGMENTS` | `false` | Nearest-neighbour reordering of segment visitation order (shortens blank travel). |
| `OPT_DEFAULT_REORDER_2OPT` | `false` | 2-opt refinement pass on top of the nearest-neighbour tour. Requires `reorder_segments`. |

---

## Warp, Brightness & Inverse Filter

Three further structs in `config.h` are persisted to NVS and edited from the WebUI or REST API. They are documented in full in [Chapter 4](04-ui-guide.md#tab-calibration) and [Chapter 5](05-optimizer.md); the storage shape is:

| Struct | Global | Contents |
| --- | --- | --- |
| `WarpConfig` | `gWarp` | `enabled`, `gridSize` (2..`WARP_GRID_MAX`), and an N × N grid of target positions in normalized [−1..1] space. Corrects **geometry** (keystone / surface shape). |
| `BrightnessConfig` | `gBrightness` | `enabled`, `gridSize`, and an N × N grid of 0–255 gains. Corrects **exposure** (throw-distance/angle vignetting). Reuses the warp grid's bilinear sampling, but is otherwise independent. |
| `InverseFilterConfig` | `gInverseFilter` | `enabled`, `regAlpha` (rolloff regularization, default `0.35`), plus a per-axis `{wnHz, zeta}` model. An axis with `wnHz <= 0` is "unmeasured" and passes through unfiltered. |

> The inverse filter's per-axis resonance model is **not** the same setting as the optimizer's shared `ring_freq_hz`/`ring_damping_ratio`: the latter only times the ZV-shaped blank jump, the former pre-filters every emitted point. They are enabled independently.

---

## pinmap.h — GPIO Assignments

All GPIO assignments are defined in `include/pinmap.h`. The following table summarizes the assignments. Pins marked **Do Not Use** are reserved by hardware and cannot be reassigned.

| GPIO | Assignment | Direction | Notes |
| --- | --- | --- | --- |
| 1 | `PIN_SD_MISO` | Input | SD card MISO on SPI3 (independent from DAC's SPI2). Pull-up recommended. |
| 2 | `PIN_FAN1_TACH` | Input | Fan 1 tacho feedback, 4.7 kΩ pull-up → +3.3V. Wired in hardware; not yet read by firmware. |
| 4 | `PIN_DMX_RX` | Input | DMX-512 receive from MAX485 RO |
| 5 | `PIN_SD_SCK` | Output | SD card SCK on SPI3 (independent from DAC's SPI2) |
| 6 | `PIN_SD_MOSI` | Output | SD card MOSI on SPI3 (independent from DAC's SPI2) |
| 7 | `PIN_LASER_R` | Output | Red laser TTL (via 6N137). Fail-safe pull-up R_FSR 10kΩ → +3.3V |
| 8 | `PIN_LASER_G` | Output | Green laser TTL (via 6N137). Fail-safe pull-up R_FSG 10kΩ → +3.3V |
| 9 | `PIN_FAN2_TACH` | Input | Fan 2 tacho feedback, 4.7 kΩ pull-up → +3.3V. Wired in hardware; not yet read by firmware. |
| 10 | `PIN_GALVO_CS` | Output | DAC8562 /SYNC (chip select) on SPI2 |
| 11 | `PIN_GALVO_MOSI` | Output | SPI2 MOSI — DAC8562 only, no longer shared |
| 12 | `PIN_GALVO_SCK` | Output | SPI2 SCLK — DAC8562 only, no longer shared |
| 13 | `PIN_DAC_CLR_N` | Output | DAC8562 /CLR — pulsed LOW at init, then HIGH |
| 14 | `PIN_WATCHDOG_OUT` | Output | Hardware watchdog heartbeat to NE555 (U12) |
| 16 | `PIN_FAN1_PWM` | Output | Fan 1 PWM (25 kHz, 8-bit) |
| 17 | `PIN_FAN2_PWM` | Output | Fan 2 PWM (25 kHz, 8-bit) |
| 15 | `PIN_ENC_A` | Input | Rotary encoder channel A |
| 18 | `PIN_ONEWIRE` | Bidirectional | DS18B20 1-Wire data. 4.7 kΩ pull-up to +3.3V required. |
| 21 | `PIN_LASER_B` | Output | Blue laser TTL (via 6N137). Fail-safe pull-up R_FSB 10kΩ → +3.3V |
| 38 | `PIN_LASER_ENABLE` | Output | Central laser enable → SSR1. HIGH only when all safety checks pass. |
| 40 | `PIN_ENC_B` | Input | Rotary encoder channel B |
| 41 | `PIN_ENC_BTN` | Input | Rotary encoder push button (optional, not populated on the reference build) |
| 39 | `PIN_SCAN_FAIL_IN` | Input | NE555 scan-fail output (U11) |
| 42 | `PIN_SD_CS` | Output | SD card chip select on SPI3 (independent from DAC's SPI2) |
| 43 | `PIN_DEBUG_TX` | Output | UART0 TX / USB CDC TX |
| 44 | `PIN_DEBUG_RX` | Input | UART0 RX / USB CDC RX |
| 47 | `PIN_ESTOP` | Input | Emergency stop (active = pin HIGH via pull-up = E-stop not pressed) |
| 48 | `PIN_STATUS_LED` | Output | Onboard RGB LED |

**Reserved — Do Not Use:**

| GPIO | Reason |
| --- | --- |
| 0, 3, 45, 46 | Strapping pins — state at boot determines boot mode |
| 19, 20 | USB D−/D+ — native USB CDC |
| 35, 36, 37 | OPI PSRAM internal connections on N16R8 — not accessible |

**Currently unassigned (free for expansion):**

GPIO 45 is free (`PIN_HEARTBEAT` is reserved for it in `pinmap.h` but commented out — uncomment only if the hardware is fitted). Everything else on the header is assigned; GPIO 2 and 9, freed when the SD card moved to SPI3, now carry the fan tacho inputs.

---

## NVS — Parameter Persistence

GalvOS uses the ESP32 NVS (Non-Volatile Storage) to persist configuration across reboots. Parameters are stored in two NVS namespaces:

| Namespace | Contents |
| --- | --- |
| `"laser"` | `RuntimeConfig` fields, optimizer profiles, safety config, Wi-Fi credentials, warp/brightness grids, inverse-filter models |
| `"projection"` | `ProjectionConfig` fields (galvo_kpps, laser power, angles, distance) |
| `"bpm"` | Manual BPM and the BPM-clock DMX channel |
| `"temp_names"` / `"temp_off"` / `"temp_unit"` | Per-sensor display names, per-sensor calibration offsets, and the WebUI temperature unit |

NVS values take priority over compile-time defaults on every boot. This means:

- Changing an `OPT_DEFAULT_*` macro in `config.h` has **no effect** if that parameter is already stored in NVS.
- To apply new compile-time defaults, you must reset NVS (see below).

Optimizer profile parameters are keyed with a per-profile suffix (`_s`, `_c`, `_w`, `_3`, `_sol`, `_sc`) pinned to the profile index — not the profile name. This means profile parameters survive renames without resetting to defaults.

---

## Resetting to Defaults

**Via WebUI:** Configuration tab → **⚠ Factory Reset** (`POST /api/factory-reset`). This clears the `"laser"` namespace — the bulk of the configuration, Wi-Fi credentials included — and restarts. Note that it does **not** touch `"projection"`, `"bpm"`, or the `"temp_*"` namespaces; use the esptool route below if you want a genuinely blank device.

**Via esptool (nuclear option):** Erase the NVS partition. With this project's `partitions.csv`, `nvs` is the **last** partition — at offset `0xF20000`, size `0x40000`:

```bash
esptool.py --port /dev/ttyUSB0 erase_region 0xF20000 0x40000
```

Confirm the offset for your build first (`pio run --target buildfs` prints the table, or read `partitions.csv`) — erasing the wrong region wipes the filesystem or an app slot. When in doubt, `esptool.py erase_flash` and reflash everything.

> **Note:** Wi-Fi credentials are stored in NVS. After a reset the device no longer knows any network, so it falls back to its own AP (SSID `Laser-XXXX`) — see [Chapter 4 → Accessing the WebUI](04-ui-guide.md#accessing-the-webui) for the credentials.

---

*Next: [Chapter 4 — UI Guide](04-ui-guide.md)*

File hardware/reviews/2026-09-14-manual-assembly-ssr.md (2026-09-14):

# Manual assembly, ESP32 pitch and SSR preselection

User update received after `1716ef8`: manual assembly by the user;
ESP32 pin pitch 2.54 mm; assistant to select the SSR; standard emergency-stop
button with two wires. These statements do not establish contact type,
row spacing, exact switched power branch or a complete safety chain.

## Accepted implementation facts

U1's schematic/PCB Assembly fields now specify manual assembly of two
1x22 female socket strips and user-confirmed 2.54 mm pitch. The local
footprint and placed footprint descriptions distinguish this confirmed
pitch from the still-provisional 22.86 mm row-center spacing and body
alignment. User-reported body remains 28 x 57 mm. No pads moved.

Manual assembly does not imply soldering-iron-only assembly. U_BUCK1 has
a concealed exposed-pad solder joint; paste plus controlled reflow/hot-air
or an appropriate assembly service is required to make that connection.
The fine-pitch packages also require appropriate tools and inspection.
No arbitrary thermal-hole/stencil redesign is inferred from “manual.”

## SSR candidate, not purchase or installation approval

Working assumption, presented to the user for confirmation: interrupt only
the nominal 12.6 V DC laser-driver feed, downstream of the supply split;
keep controller/buck and fans supplied. If the intended switch point is
the AC mains input instead, this selection does not apply. No mains routing
or wiring changes have been made.

Manufacturer-verified candidate:
**Omron G3NA-D210B-UTU DC5-24**, external panel-mount DC SSR with screw
terminals. The similarly named AC-output G3NA-210B is not interchangeable.
The DC-output variant also has an AC-input option; order the DC5-24 version.

Primary source: [Omron G3NA datasheet J166-E1-15](https://assets.omron.eu/downloads/latest/datasheet/en/j166_g3na_solid_state_relays_datasheet_en.pdf),
ordering table p. 2, ratings p. 4, characteristics p. 5 and terminal drawing
p. 9. PDF SHA-256:
`b903bb5c8ae99b42c645a991f7aa08d6ae9b7855b9a79aa9583a767195cd9da3`.
Manufacturer ratings table was visually checked, not inferred from search
snippets. Stock, price and current purchasing availability were not checked.

- DC output: rated 5–200 VDC, load-voltage range 4–220 VDC.
- Control: rated 5–24 VDC, operating 4–32 VDC, 5 mA maximum input current;
  must-operate threshold 4 V maximum.
- Nameplate 10 A is conditional: the datasheet specifies 0.1–10 A with
  its specified heatsink at 40 C, versus 0.1–4 A without. These are
  manufacturer limits, **not a GalvOS load/thermal qualification**.
- Output drop up to 1.5 V; off-state leakage up to 5 mA at the specified
  200 VDC test point. Do not extrapolate an exact leakage at 12.6 V.
  Driver undervoltage tolerance and OFF behavior remain unqualified.

### Existing control connection is not a verified match

The current NE555 output drives J_SSR1 through 330 ohms. Even an ideal
5.0 V source, with the SSR's permitted 5 mA input, leaves only
5.0 - 0.005 * 330 = 3.35 V at the input, below the 4 V guaranteed-operate
requirement. The real NE555 output cannot improve that upper-bound case.
Therefore this is **not a drop-in SSR for the existing J_SSR1 drive**.

A separately designed default-OFF transistor control stage powered by a
qualified supply is required before adopting this candidate. It must be
co-designed with the independent inhibit and rearm behavior. No stage has
been silently inserted and no 330-ohm resistor has been bypassed.

### Emergency-stop requirement

For a two-wire stop loop, require a latching button with a positively
opening NC contact: closed when released; open when pressed or on a broken
wire. “Two wires” alone does not prove those properties. Wire shorts and
SSR short-circuit failures are not detected or made safe by this one contact.

The current GPIO47 sampling accepts open/HIGH as OK; override can bypass
the stop decision. A normally-closed button must not simply be connected
and assumed safe with the current firmware. Required firmware logic and
the hardware shutdown architecture still need coordinated redesign.
A single ordinary SSR is not the sole safety-disconnection element for a
Class 4 laser: it can fail conductive and has off-state leakage. Independent
emission interruption and deliberate rearm remain mandatory design gates.

## Verification and preservation

Four text lines change across SCH, PCB and the local module footprint:
U1 Assembly in SCH/PCB and its two footprint descriptions. Full-file
comparison against the intended text replacements proves all other bytes
unchanged. Fresh XML subtrees for components, library definitions, library
links and nets match the previous canonical export after removing only
U1's changed Assembly metadata. All 122 components and 110 nets are retained.

ERC: zero findings. DRC/refill/parity: zero errors, zero unconnected items,
zero parity issues, one existing U_BUCK1 footprint-type warning. Seven
interface checkers and all 49 hardware unit tests pass. Project rules
unchanged. Refreshed canonical PDF; PCB renderings stay current because
all visible geometry is unchanged. No firmware/KiBot edits or Gerbers.

Current SHA-256:
- SCH: `8c1796266cc1843ee5e76cb9ab3a1025354a36771a9495bd96aa1e50c6ad0cc5`
- PCB: `b8111d778abc5b57ec3adb1bbc94060598fb87cc0d16e584e53e28c0bce4f47a`
- Local module footprint: `b6a6ffaeb4a56d3c07c6fcec29101eeb58c7d726a7576d771dc96b1c77a0ef10`
- PDF: `bbfc5fb4335a76f11f08f506cf9931459e7073332e4c70010572443b0927156e`
- PRO unchanged: `dc77f4155067018d81c509e667ad67642031a5cf69abe7181144c19c11bd3b1b`

Thermal/load/timing work remains excluded except for the essential
manufacturer limit disclosures needed to avoid misrepresenting the requested
SSR selection. No output-load qualification or production release.

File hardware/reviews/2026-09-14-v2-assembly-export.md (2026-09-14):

# V2.0.10 assembly-export and buck-pad review — 2026-09-14

Baseline: `3468b7b13f6fd5958f94450dff0705a5b9c341e0`.
**DRAFT — NOT FOR FABRICATION OR LASER OPERATION.**

## Confirmed export hazard and guard

Native KiCad 10.0.6 position exports from the current PCB give:

| Export options (CSV, mm, both sides) | Rows | U_BUCK1 |
|---|---:|---|
| `--smd-only --exclude-dnp` | 97 | Included |
| Above plus `--exclude-fp-th` | 96 | Missing |

The latter flag excludes any footprint containing a plated through-hole
pad, not just through-hole components. U_BUCK1 is correctly an SMD assembly
component despite its eight plated pad-9 holes. Changing its footprint
attribute to THT to suppress the DRC warning would misstate assembly intent.

Added `hardware/tests/check_smd_placement_coverage.py` in the existing
hardware verification layer. It derives the expected populated SMD inventory
from the actual PCB attributes, respects DNP/position-exclusion flags and
compares CSV reference uniqueness, full reference coverage, values, footprint
item names and assembly sides. It does not infer assembly type from holes.

The 97-row native export passes. The actual 96-row negative export is
rejected specifically for missing U_BUCK1. Eight unit-test methods cover
complete/empty inventories, missing buck, duplicates, extra parts, malformed
rows and identity/side mismatch. All 49 hardware unit tests pass.

This is coverage/identity proof only. Coordinates, rotation, origin, units,
supplier-specific package rotations, board-side conventions, stencil, BOM
procurement and solder-joint quality still require manufacturing review.
No KiBot configuration/workflow changes were made; the observed failure is
a native CLI option hazard, not a claim that KiBot currently uses that flag.

## Buck land-pattern evidence: no automatic geometry change

The actual placed U_BUCK1 footprint has:

- Eight signal pads at 1.27 mm pitch, 5.4 mm row-center spacing,
  each 1.55 x 0.60 mm.
- Pad-9 front/back copper regions of 2.95 x 4.90 mm, connected to
  `5V GND Buck`.
- Separate 2.60 x 3.10 mm central F.Mask and F.Paste rectangles.
- Eight 0.30 mm plated holes on pad 9, at X = +/-0.65 mm and
  Y = +/-0.65 / +/-1.95 mm, with 0.60 mm copper lands.
- No B.Mask opening in the footprint. Four central holes fall inside the
  explicit front mask/paste opening; a generic tenting setting alone does
  not remove that opening or establish hole filling.

Source: TI [LMR33630 datasheet](https://www.ti.com/lit/ds/symlink/lmr33630.pdf),
DDA0008J board/stencil examples, drawing 4221637/B, 03/2016. Examined PDF
SHA-256: `3b0920a4e56a0b3f5f214a6317d3c06cff6e541e5054024adc31c30acc50c04a`.

The example explicitly shows the same signal-pad geometry, extended copper
and 2.60 x 3.10 mm mask/paste opening. Its stencil table associates that
opening with 0.125 mm stencil thickness and explicitly describes 100% printed
coverage. Therefore neither the extended copper nor the single full opening
is by itself evidence of an error. Do not substitute an arbitrary segmented
stencil merely to follow a generic rule.

The TI board example labels its vias 0.20 mm typical, whereas the placed
footprint drills are 0.30 mm. The assembly shop must review the actual via,
mask, stencil and solder process together, including possible paste loss
into unfilled holes. TI also states that the exposed pad must be soldered
to the board and that the assembly site may recommend a different stencil.
Exact purchased package variant, process and inspection remain unqualified.
No thermal or current-capacity conclusion is made.

## BOM evidence and required user choice

A fresh ungrouped native BOM export contains 122 rows. Only eight rows have
an explicit MPN or legacy MP field. Some other Value fields already identify
specific ICs; the field count is not proof that 114 parts are unidentified
or that the eight populated fields are procurement-qualified.

The user was asked whether assembly will use a reflow service, self-applied
paste/hot air, or mainly a soldering iron. Do not choose a different buck,
stencil or via construction before this process choice is known. The
exposed-pad joint is a required connection, not optional assembly detail.

## Reproduce without manufacturing release

Run from the repository root, using a fresh temporary directory:

```sh
assembly_check_dir=$(mktemp -d /tmp/galvos-assembly-check.XXXXXX)
kicad-cli pcb export pos --format csv --units mm --side both \
  --smd-only --exclude-dnp --output "$assembly_check_dir/smd.csv" \
  'hardware/schematics/Laser Controllerv2_only_for_pcb_test.kicad_pcb'
/usr/bin/python -B hardware/tests/check_smd_placement_coverage.py \
  "$assembly_check_dir/smd.csv" \
  'hardware/schematics/Laser Controllerv2_only_for_pcb_test.kicad_pcb'
python -B -m unittest discover -s hardware/tests -p 'test_*.py'
```

For the negative integration test, repeat the export with
`--exclude-fp-th` and a different output filename. The guard must fail
with `missing=['U_BUCK1']`. Do not send that export for assembly.

SCH/PCB/PRO hashes remain respectively
`adb9bf0af905d7a063de0bc2b287c3bc65b554794207a8d884ebd85c7f033f29`,
`267c312d4451f386fe3bcb2e500c779456d1787064c24c7be033837a4de578ee`,
`dc77f4155067018d81c509e667ad67642031a5cf69abe7181144c19c11bd3b1b`.
PDF/PCB images remain current and unchanged. Prior ERC/DRC evidence applies
to these identical design files; no new ERC/DRC run is claimed here.

No production BOM, Gerbers or assembly release was generated. Probe CSVs
remain temporary. Mechanical fit, independent safety and other release
gates remain open. Thermal, load and timing remain excluded and unverified.

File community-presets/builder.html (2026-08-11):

# GalvOS Community Preset Builder

Offline preset tuner & point/curve editor for the Mikoy laser show controller — no backend, exports device-loadable JSON.

🎲 Surprise Me

## Scanner Settings

Scanner Speed (kpps)

Target FPS

Max Points/Frame

Hard cap 1300 (device MAX_PTS_PER_FRAME_CEILING).

0 / 1300 pts — estimated after optimizer: ~0

## Color

Default / Active Color

Use col_override (intermediate values)

R

G

B

col_override only valid if preset supports it in firmware.

## Metadata

Preset Name *

Author

HW Tested

Tested at kpps

Galvo Model

Notes

FW Version

Based On

## Export / Import

Export Device JSON Export C++ Snippet Save Session JSON Import JSON

Simple Mode Advanced Mode

### Base Preset

Load Built-in Preset (81 available)

Speed

140

Size

200

### Optimizer Profile

Named Profile

Real per-profile tuned defaults from firmware config.h. Pick "Custom" to edit raw fields.

Raw optimizer_profile fields

Point Sequence / Math Function output has no on-device format — built-in presets are fixed C++ generators. Use Export C++ Snippet to hand-paste into preset_patterns.cpp, or Save Session JSON to keep working on it later.

Math Function Editor (X/Y parametric, t ∈ [0, 2π])

X(t)

Y(t)

Sample Points

Live Preview Convert to Point List

Snap to grid Close path Point indices Corner dwell warnings Optimizer ghost preview Clear

Click empty space: add point · drag: move · right-click: delete · shift+click an edge: insert · scroll: zoom · middle-drag: pan

### Points (0)

Select a point to edit it.

### C++ Snippet

Copy to clipboard

Standalone tool · works offline · no cookies, no localStorage, no external calls.

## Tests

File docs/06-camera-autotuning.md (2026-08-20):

# Chapter 6 — Camera-in-the-Loop Auto-Tuning

*Previous: [Chapter 5 — The Optimizer](05-optimizer.md)*

> Chapter 5 explained what the optimizer does. This chapter explains how to stop guessing at its parameters by hand and let a camera and a search algorithm do it instead. Turning `max_corner_pts` up by one, projecting, squinting at the beam, turning it back down — that loop gets old fast. This one replaces the squinting with a webcam and a cost function.

## Table of Contents

- [What This Is](#what-this-is)
- [The Bench Setup](#the-bench-setup)
- [Requirements](#requirements)
- [Installation](#installation)
- [Files](#files)
- [The Camera Patterns](#the-camera-patterns)
  - [Why Trails has no camera pattern](#why-trails-has-no-camera-pattern)
- [The Shutter Must Span a Whole Frame](#the-shutter-must-span-a-whole-frame)
- [Workflow](#workflow)
  - [0. wizard](#0-wizard)
  - [1. check](#1-check)
  - [2. preview](#2-preview)
  - [3. calibrate](#3-calibrate)
  - [4. measure](#4-measure)
  - [5. optimize](#5-optimize)
  - [6. diagnose](#6-diagnose)
  - [7. autotune-camera](#7-autotune-camera)
  - [8. autotune-colors](#8-autotune-colors)
  - [9. regress](#9-regress)
  - [Standalone: analyze-live](#standalone-analyze-live)
  - [Standalone: calibrate-warp](#standalone-calibrate-warp)
  - [Standalone: measure-resonance](#standalone-measure-resonance)
  - [Standalone: tune-dac-range](#standalone-tune-dac-range)
- [How Scoring Works](#how-scoring-works)
- [Session Semantics — Nothing Sticks Until You Apply It](#session-semantics--nothing-sticks-until-you-apply-it)
- [Safety](#safety)

---

## What This Is

The firmware exposes a REST API, `/api/calib-cam/*`, that lets an external program select a calibration pattern, live-override the active optimizer profile's parameters (RAM-only, never touching NVS), and read back exactly what has changed. `scripts/optimizeGalvo/optimizeGalvo.py` is the program that actually drives it: it opens a mono/global-shutter USB camera, projects one of nine reference patterns, measures the result, and runs an [Optuna](11-glossary.md) search to find the parameter combination that produces the cleanest beam.

This is **not** a replacement for the manual Galvo Calibration card in the WebUI (Chapter 4) — offset, gain, swap, and invert are still set by hand, because those are fixed hardware/wiring properties, not something a search should be exploring every run. What this tool auto-tunes is the **optimizer**: corner dwell, blanking, resample, ringing compensation — the parameters in [Chapter 5](05-optimizer.md#parameter-reference) that trade off against each other and are genuinely tedious to hand-tune by eye.

It replaces the closing item in [Chapter 10's Planned Features](10-known-issues-and-todos.md#planned-features) — "auto-tuning via global shutter camera" was the plan; this is the implementation.

---

## The Bench Setup

What this actually looks like on the bench: the target board sits on a stand facing the projector, with the mono/global-shutter camera clamped alongside it, aimed at the flat target surface the beam is projected onto.

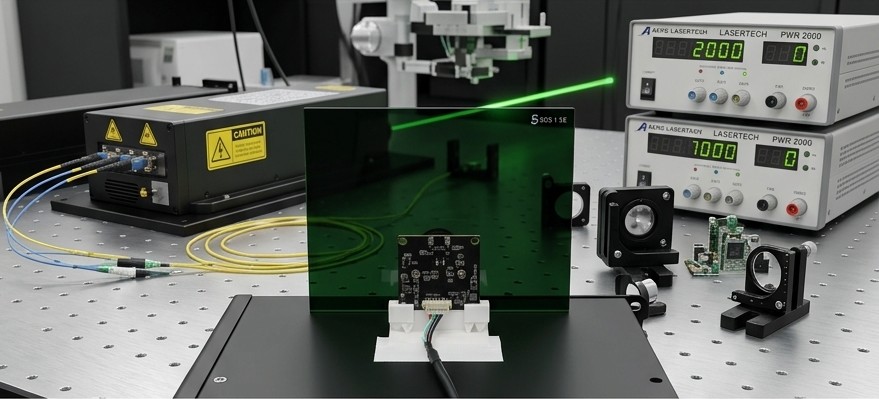
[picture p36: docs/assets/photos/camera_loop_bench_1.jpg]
Camera-in-the-loop bench setup — projector, target board, and sensor/interface PCB


The small board mounted below the target is the sensor/interface PCB — it carries the camera's own driver electronics, separate from the GalvOS controller itself, which drives the projector over the network as described in [Requirements](#requirements).

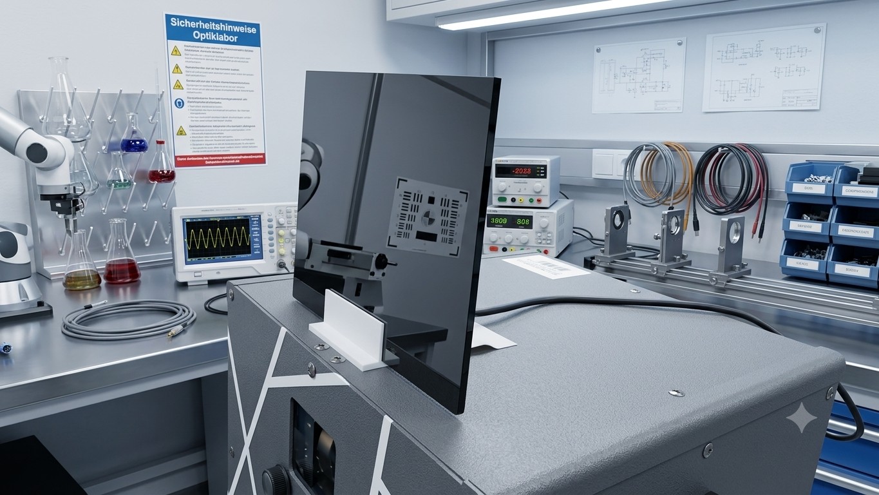
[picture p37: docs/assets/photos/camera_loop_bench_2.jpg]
Camera mounted on the target rig, aimed at the projection surface


Camera and target share one rigid mount so the pixel→DAC [homography](11-glossary.md) solved by `calibrate` (see [Workflow](#workflow) below) stays valid between runs — nudging either one out of alignment is exactly the "re-run `calibrate`" case called out there.

---

## Requirements

- A mono or global-shutter USB camera. The tool was built and tested against an **OV9281**-based module — a rolling-shutter webcam will smear a fast-moving beam and produce misleading measurements.
- A GalvOS device reachable over the network, with the `/api/calib-cam/*` API (any current firmware).
- Python 3.12 or 3.13 is the safest bet — if wheels for `opencv-python`/`optuna`/`numpy` aren't published yet for your interpreter version, use a 3.12/3.13 v-env rather than fighting a source build.
- The ESP32 and the machine running the script on the same network, with a known base URL (hostname or IP).

## Installation

```bash
cd scripts/optimizeGalvo
python -m venv .venv
.venv\Scripts\activate        # or: source .venv/bin/activate
pip install -r requirements.txt
```

`requirements.txt`: `opencv-python`, `numpy`, `optuna`, `requests`.

## Files

| File | Purpose |
| --- | --- |
| `camConfig.json` | Runtime config — ESP32 base URL, camera index/resolution/exposure, DAC calibration range, cost weights, diagnose thresholds, HTTP timeout/retry settings, per-profile camera overrides (`profileCamera`, see [autotune-camera](#7-autotune-camera)). Created by `wizard` on first run. |
| `homography.npz` | Pixel→DAC homography matrix plus the stored background frame, written by `calibrate`. Required by `measure`, `optimize`, and `diagnose`. |
| `searchSpace.json` | Parameter ranges per camera-tunable optimizer profile (`Vector`, `Smooth`, `Waves`, `MultiObject`, `Wireframe`, `Text`, `Particles`). Regenerated with sensible defaults by `optimize`/`diagnose --autotune` if missing (same first-run behavior as `camConfig.json`) — edit the result if you widen a parameter's firmware-side limits. An **existing** file is never rewritten, so one created before v6.75.0 has no `Wireframe`/`Text`/`Particles` block and those profiles are silently skipped by `optimize`; the tool warns when it detects this — delete the file to regenerate it, or copy the missing blocks in by hand. |
| `results/` | `optuna_study.db` (resumable search state), per-trial `.jsonl` logs, best-parameter JSON snapshots, and saved camera frames from `measure`/`calibrate`., interactive runs offer to clean up stale files here (everything except the `.db`) at startup. |

Override the config path with `--config`, e.g. to keep separate configs for multiple camera rigs.

## The Camera Patterns

Nine patterns exist on the firmware side purely for this tool (`calib_patterns.cpp`, indices 11–16 and 21–23), geometrically matching the ground truth the script rasterizes internally so measured error is directly comparable to the ideal:

| Pattern | Profile | Used for |
| --- | --- | --- |
| `corners4` | — | 4 static dots at the DAC-range corners — the homography reference. Uses a fixed manual dwell so it stays camera-visible regardless of what corner-dwell overrides a search throws at it. |
| `square` | Vector | Sharp 90° corners — corner hotspot + path deviation. |
| `star` | Vector | 5-point pentagram (self-intersecting) — corner hotspot + path deviation. |
| `segments` | MultiObject | 4 parallel vertical lines — blank-jump leakage between disconnected strokes. |
| `circle` | Smooth | Continuous curve, no real corners — path deviation + brightness uniformity. |
| `spiral` | Waves | Dense continuous curve — path deviation + brightness uniformity under high interior density. |
| `wireframe` | Wireframe | Projected cube drawn as 4 open 3-edge chains — corner hotspot, path deviation, and blank leakage on the jumps between chains. |
| `text` | Text | The fixed string `GAL` through the real stroke font (`text_renderer.cpp`) — same metrics as `wireframe`, on many short strokes instead of a few long ones. |
| `particles` | Particles | 12 isolated dwell dots at graded jump distances (10k–36k DAC units) — blob count, blob elongation, and blob centroid error. |

The last three (firmware v6.75.0) close the gap for the three profiles that previously had no camera pattern at all. `wireframe`/`text` are scored as paths; `particles` is scored as **dots**, which is a genuinely different measurement — see [How Scoring Works](#how-scoring-works).

`particles` is the pattern that would have caught the v6.65.1 Starfield regression, where a Particles blank window sized for short hops left the beam still in flight when the laser re-armed and painted "connect the dots" streaks. Each of its dots is a degenerate two-vertex open segment, so its dwell comes entirely from the live profile's `max_corner_pts` — unlike `corners4` there is deliberately **no** fixed-dwell override, because the dwell is part of what is under test.

### Why Trails has no camera pattern

`OPT_PROFILE_TRAILS` is the one profile that is not camera-tunable, and this is a property of the profile, not a missing feature.

Every metric in this tool compares one accumulated camera frame against one static rasterized ideal. A Trails preset's ground truth is not a shape — it is a **trajectory over time**: a head plus a tail whose brightness decays with age. A single accumulated exposure integrates the whole tail into the same image as the head, so:

- The "ideal" a scorer would compare against is not defined without also modelling exposure time, decay rate, and where in the animation phase the shutter opened.
- Path deviation and corner hotspot would read the decaying tail as legitimate lit path, i.e. the correct behavior and the streak defect look identical.
- The dot metrics do not apply either — a trail is not a set of isolated blobs.

A static proxy pattern (some fixed shape run under the Trails profile) could be written, and it would produce numbers. It would not be measuring Trails: the profile's distinguishing parameters are exactly the ones that govern how a *moving* head and a *fading* tail behave, and a static shape exercises none of them. A number that does not respond to the thing you are tuning is worse than no number, so none is produced.

Tuning Trails correctly would need a fundamentally different rig — a high-frame-rate camera synchronized to the frame boundary, scoring a sequence rather than an accumulation. That is out of scope for this tool. Until then, Trails stays on hand tuning via the WebUI Optimizer tab.

`/api/calib-cam/start` accepts a `channel` field (default: **blue**, channel 3) instead of always drawing white. A mono camera can see the R/G/B beams smear apart or land at slightly different positions if the laser diodes aren't perfectly co-bore sighted — measuring on one channel avoids that artifact entirely. `optimizeGalvo.py` drives this from `camPatternChannel` in `camConfig.json`.

---

## The Shutter Must Span a Whole Frame

A vector-scanned pattern only exists as a shape when integrated over a whole frame — at any instant the beam is at exactly one point. A shutter shorter than one frame period therefore does not capture a dim version of the shape. It captures a **random slice of the scan path**, and stacking more of those slices does not fix what each one is missing.

This is a physical constraint, not a tuning preference, so `exposure` is **derived, not searched**. Before any command that scores a capture (`measure`, `optimize`, `diagnose`, `regress`, `autotune-camera`), the tool measures how long one full traversal of the pattern actually takes and raises the shutter to cover it:

```text
frame period = /api/optimizer-stats  planned_total   (points in the frame)
             / /api/state            points_per_sec  (real measured output rate)
```

Both terms are measured rather than modelled, so the result already carries any shortfall between commanded and achieved output rate. Measured on this rig, every calib pattern lands between 15 and 29 ms per pass, which needs `exposure` −4 (62.5 ms) — against the −11 (0.488 ms) an earlier `autotune-camera` run had settled on.

`points_per_sec` is read **twice**, spaced far enough apart to cover a full averaging window, and only the second read is trusted. `galvo_out.cpp`'s `pointsPerSec()` recomputes at most once a second, over the interval since whoever polled it last — so a first read after a long silence describes a window the tool never observed, and past roughly 95 s of silence at 45 kpps its `delta × 1000` overflows `uint32` and returns a wrapped value. Seen live: a first read after several minutes idle reported ~4.8 kpps instead of 45 kpps, inflating `square` from 26.8 ms to 251.6 ms and driving the derived shutter to −1 (500 ms) — long enough to nearly saturate the background by itself.

### Why this had to be taken away from the search

At −11 each capture saw **1.7 % of the scan path**. Even max()-accumulated over `accumFrames: 24` that topped out near 33 %, which is exactly the "the square photographs as a dashed square" artifact. The search could not have found its way out on its own: `autotune-camera`'s cost rewards low saturation and a dark background, and a too-short shutter delivers both beautifully while quietly capturing almost nothing. No additional cost term fixes that — the constraint is physical, so it belongs outside the search.

Worse than the missing coverage: at 1.7 % duty a pixel's value is the beam's *instantaneous* intensity in whichever slice caught it, **not its dwell time**. Every intensity-derived metric depends on dwell — `cornerHotspot` (a corner is hot because the beam lingers there), `brightnessNonUniformity`, and both `blankLeakage` terms (a fast jump trail should read as a *dim* streak, but at 1.7 % duty it reads full-brightness-or-absent). Those metrics were measuring noise.

### Stacking frames is not the alternative

A common instinct is to raise `accumFrames` instead, and to worry that stacking averages real artifacts away. Both are backwards:

- `grabAccumulated()` uses `np.maximum`, not a mean. It keeps the peak value ever seen per pixel, so nothing is averaged away — a blank-jump trail present in any one frame survives at full brightness.
- A short shutter is what *loses* artifacts. A blank jump is a within-frame event lasting tens of microseconds; at 1.7 % duty you have a ~1.7 % chance per shot of catching it. A full-frame shutter integrates every jump in that frame, every time.

`accumFrames` therefore stops being a coverage mechanism. Its default dropped **24 → 8**: with each frame already complete, stacking only evens out the 1-vs-2-pass banding you get because the shutter isn't phase-locked to the laser (a 62.5 ms shutter spans ~2.2 passes of a 28 ms pattern, so some pixels are drawn twice and some once). A longer shutter *and* fewer frames is still net faster than before — 8 frames at 16 fps is 0.5 s, against 24 at 24 fps.

### The light budget

Going −11 → −4 integrates **128× more light** per capture. Cut it optically, never by shortening the shutter again:

| Method | Notes |
| --- | --- |
| ND filter, ~2.1 OD (7 stops) | Best — keeps the sensor response linear and doesn't touch the thing under test |
| Stop the lens down | f/2 → f/22 is ~120×, if the lens has an iris |
| `master_dimmer` | Last resort: 8-bit and gamma-curved, and diode lasers go nonlinear at very low current, which distorts the photometry you just recovered |

`saturationFrac` (weight 3.0 in `costWeights`) polices whatever residual clipping remains.

### Configuration and escape hatches

| Key | Default | Meaning |
| --- | --- | --- |
| `exposureFromFrameRate` | `true` | Derive the shutter from the measured frame period. Set `false` only to reproduce a pre-2.25.0 measurement. |
| `exposureFrameMargin` | `1.25` | Require the shutter to span this many passes, not just one — the point count drifts as `optimize` searches, and derivation runs once per run. |
| `exposure` | `-11` | Now only a **floor**. The effective value is `max(configured, derived)`, so a deliberately longer shutter is still honored. |
| `minPathCoveragePct` | `60.0` | Was `10.0`, set below the undersampled captures it should have been rejecting — which is why nothing ever flagged this. With a full-frame shutter a correct capture sits at 95–100 %. |

Two independent checks enforce it. `resolveExposure()` derives the shutter once per run against a reference pattern set; `measureOnce()` then re-checks the *actual* period of every single capture, so a pattern whose point count pushes it past that derivation cannot slip through silently. A per-profile `profileCamera` override may only ever **lengthen** the shutter — an override tuned under the old regime cannot hand one profile back the sub-frame shutter every other profile was just protected from.

If the frame period can't be measured at all, the tool warns and leaves your configured value alone rather than guessing one.

## Workflow

Run `optimizeGalvo.py <command> --help` for any command's full description; the summaries below are the short version. Two flags apply across most commands: `--no-view` (disable the live camera preview window, e.g. for headless runs) and `--zoom {1,2,3}` (digital zoom on that window, live-adjustable with the `1`/`2`/`3` keys).

### 0. wizard

Interactive first-run setup — prompts for ESP32 base URL, camera index/resolution, exposure, DAC calibration range, and HTTP timeout, showing current/default values in brackets. Runs automatically the first time any command is used with no config file yet; run it directly later to change settings.

### 1. check

```bash
python optimizeGalvo.py check
```

GETs `/api/status` and prints firmware version, network info, and safety-interlock state. Opens no camera — run this first whenever something isn't working, to rule out a wrong base URL or a WiFi/mDNS problem before chasing camera or optics issues. Exits 1 on failure.

### 2. preview

```bash
python optimizeGalvo.py preview
```

Live grayscale feed with saturation %, peak pixel value, and measured fps overlaid. `+`/`-` adjust exposure live (auto-saved), `1`/`2`/`3` zoom, `s` saves a snapshot, `space` freezes the frame, `q` quits. Use this to physically aim/focus the camera and dial in exposure — visible beam trace, not blown out — before calibrating.

### 3. calibrate

```bash
python optimizeGalvo.py calibrate
```

Captures a dark background, projects `corners4`, detects the four dots, and solves the pixel→DAC homography, saving it (with the background) to `homography.npz`. Required once before `measure`/`optimize`/`diagnose`; re-run whenever the camera or projection surface moves. Saves a labeled snapshot marking which dot was identified as TL/TR/BR/BL — check it against the real physical layout if later measurements look rotated or mirrored.

### 4. measure

```bash
python optimizeGalvo.py measure --pattern square
```

Projects one pattern with currently-live parameters, captures, and prints path-deviation RMS, blank-leakage, corner hotspot, brightness non-uniformity, and the weighted cost. `--pattern` accepts any of the eight non-`corners4` patterns above; `particles` prints the blob metrics instead of corner hotspot. Requires `homography.npz`.

### 5. optimize

```bash
python optimizeGalvo.py optimize --profile Vector --trials 40 --apply
```

The main event. Queries the ESP32 for its optimizer profiles and preset membership, runs one Optuna study per selected profile against its `searchSpace.json` ranges, and prints a before/after report — every parameter marked changed, unchanged-not-searched, or unchanged-behind-a-disabled-gate. Each trial calls `/api/calib-cam/params` with candidate values and sums the cost across the profile's pattern(s).

- `--profile Vector,Smooth` or `--profile all` selects profiles directly; `--preset "Milky Way"` tunes whichever profile drives a named preset instead (errors out for Trails — see [Why Trails has no camera pattern](#why-trails-has-no-camera-pattern)). Omit both for an interactive menu.
- Studies persist in SQLite (`--storage`, default `results/optuna_study.db`) under `--study-name` (default: the profile name) — Ctrl+C or a crash loses nothing, just re-run the same command to resume. `--fresh` starts over instead.
- `--apply` applies the winning values to the ESP32 and persists them via `/api/optimizer-save` without asking. **Without it, results only go to the JSON file** — see [Session Semantics](#session-semantics--nothing-sticks-until-you-apply-it).
- `space` pauses between trials, `q` aborts early (like Ctrl+C; completed trials are kept).

### 6. diagnose

```bash
python optimizeGalvo.py diagnose --profile all --autotune
```

Measures each selected profile's current live output (no overrides — a read, not a search) and classifies it: **OK**, a **geometry issue** (size/position off vs. ideal — points at galvo gain/offset drift or a moved camera, fix with the Calibration tab or re-running `calibrate`, not by retuning), or an **optimizer settings issue** (path deviation/leakage/hotspot/uniformity out of tolerance while geometry is clean — genuinely fixable by tuning). `--autotune` runs `optimize` automatically on anything flagged with a settings issue, with the same `--trials`/`--study-name`/`--storage`/`--apply` options.

### 7. autotune-camera

```bash
python optimizeGalvo.py autotune-camera --trials 30 --apply
```

Tunes the camera's own **capture** settings — gain, `binaryThreshold`, `accumFrames` — instead of firmware parameters, which are left exactly as currently live. `exposure` is deliberately **not** in the search: it is fixed by the laser's frame period, for the reasons in [The Shutter Must Span a Whole Frame](#the-shutter-must-span-a-whole-frame). Useful when `measure`/`diagnose` results look inconsistent for reasons that turn out to be the camera, not the beam: washed-out captures, blooming, background noise. Saturated pixels are flagged as their own metric (`saturationFrac`) — a global-shutter sensor blooms into neighboring pixels at saturation, which can otherwise inflate path-deviation/corner-hotspot readings with a camera artifact rather than a real scan problem; `diagnose` will suggest running this command instead of `optimize` when it detects that. On apply, updates `camConfig.json` and refreshes `homography.npz`'s stored background to match the new exposure/gain (background is exposure-dependent, so a stale one would corrupt every later diff-subtraction).

By default it measures against `square`/`circle`/`segments` — a reasonable general-purpose set, but a poor fit for any profile whose pattern sits at a very different lit duty cycle than those three (e.g. `particles`, made of isolated sub-millisecond dwells at ~38% lit against `square`/`circle`'s ~97-99%): a shutter/threshold tuned on the bright default set can end up shorter than a single dot and capture almost nothing of the sparse one. `--profile <name>` scopes the whole run to that firmware profile — defaults `--patterns` to the profile's own pattern(s), tunes against the *dimmest searchable configuration* of that profile rather than whatever happens to be live (so the tuned settings don't go blind the moment `optimize` searches toward a smaller/dimmer point), and on apply saves the result under `camConfig.json`'s `profileCamera[<name>]` instead of overwriting the global capture settings. `optimize`/`measure`/`diagnose` then apply a profile's `profileCamera` override automatically (with a fresh background grab) whenever that profile is what's being measured, leaving every other profile on the global settings. `--patterns` overrides the pattern set directly, with or without `--profile`.

A capture that sees nothing at all (`cost` scored at the fixed `blindCapture` weight) can no longer win a trial outright — only among trials that actually saw the beam is the best one chosen, so a too-short shutter/too-high threshold can no longer look like the answer just because it produced a clean, empty frame.
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

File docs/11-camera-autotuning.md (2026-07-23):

# Chapter 11 — Camera-in-the-Loop Auto-Tuning

> Chapter 5 explained what the optimizer does. This chapter explains how to stop guessing at its parameters by hand and let a camera and a search algorithm do it instead. Turning `max_corner_pts` up by one, projecting, squinting at the beam, turning it back down — that loop gets old fast. This one replaces the squinting with a webcam and a cost function.

## Table of Contents

- [What This Is](#what-this-is)
- [Requirements](#requirements)
- [Installation](#installation)
- [Files](#files)
- [The Camera Patterns](#the-camera-patterns)
- [Workflow](#workflow)
  - [0. wizard](#0-wizard)
  - [1. check](#1-check)
  - [2. preview](#2-preview)
  - [3. calibrate](#3-calibrate)
  - [4. measure](#4-measure)
  - [5. optimize](#5-optimize)
  - [6. diagnose](#6-diagnose)
  - [7. autotune-camera](#7-autotune-camera)
- [How Scoring Works](#how-scoring-works)
- [Session Semantics — Nothing Sticks Until You Apply It](#session-semantics--nothing-sticks-until-you-apply-it)
- [Safety](#safety)
- [Version History](#version-history)

---

## What This Is

Firmware v6.03.0 added a REST API, `/api/calib-cam/*`, that lets an external program select a calibration pattern, live-override the active optimizer profile's parameters (RAM-only, never touching NVS), and read back exactly what has changed. `scripts/optimizeGalvo/optimizeGalvo.py` is the program that actually drives it: it opens a mono/global-shutter USB camera, projects one of six reference patterns, measures the result, and runs an [Optuna](10-glossary.md) search to find the parameter combination that produces the cleanest beam.

This is **not** a replacement for the manual Galvo Calibration card in the WebUI (Chapter 4) — offset, gain, swap, and invert are still set by hand, because those are fixed hardware/wiring properties, not something a search should be exploring every run. What this tool auto-tunes is the **optimizer**: corner dwell, blanking, resample, ringing compensation — the parameters in [Chapter 5](05-optimizer.md#parameter-reference) that trade off against each other and are genuinely tedious to hand-tune by eye.

It replaces the closing item in [Chapter 9's Planned Features](09-known-issues-and-todos.md#planned-features) — "auto-tuning via global shutter camera" was the plan; this is the implementation.

---

## Requirements

- A mono or global-shutter USB camera. The tool was built and tested against an **OV9281**-based module — a rolling-shutter webcam will smear a fast-moving beam and produce misleading measurements.
- GalvOS firmware ≥ v6.04.1 (for per-channel pattern color; v6.03.0 works but always draws white).
- Python 3.12 or 3.13 is the safest bet — if wheels for `opencv-python`/`optuna`/`numpy` aren't published yet for your interpreter version, use a 3.12/3.13 venv rather than fighting a source build.
- The ESP32 and the machine running the script on the same network, with a known base URL (hostname or IP).

## Installation

```bash
cd scripts/optimizeGalvo
python -m venv .venv
.venv\Scripts\activate        # or: source .venv/bin/activate
pip install -r requirements.txt
```

`requirements.txt`: `opencv-python`, `numpy`, `optuna`, `requests`.

## Files

| File | Purpose |
| --- | --- |
| `camConfig.json` | Runtime config — ESP32 base URL, camera index/resolution/exposure, DAC calibration range, cost weights, diagnose thresholds, HTTP timeout/retry settings. Created by `wizard` on first run. |
| `homography.npz` | Pixel→DAC homography matrix plus the stored background frame, written by `calibrate`. Required by `measure`, `optimize`, and `diagnose`. |
| `searchSpace.json` | Parameter ranges per camera-tunable optimizer profile (`Vector`, `Smooth`, `Waves`, `MultiObject`). Edit this if you widen a parameter's firmware-side limits. |
| `results/` | `optuna_study.db` (resumable search state), per-trial `.jsonl` logs, best-parameter JSON snapshots, and saved camera frames from `measure`/`calibrate`. |

Override the config path with `--config`, e.g. to keep separate configs for multiple camera rigs.

## The Camera Patterns

Six patterns exist on the firmware side purely for this tool (`calib_patterns.cpp`, indices 11–16), geometrically matching the ground truth the script rasterizes internally so measured error is directly comparable to the ideal:

| Pattern | Used for |
| --- | --- |
| `corners4` | 4 static dots at the DAC-range corners — the homography reference. Uses a fixed manual dwell so it stays camera-visible regardless of what corner-dwell overrides a search throws at it. |
| `square` | Sharp 90° corners — corner hotspot + path deviation. |
| `star` | 5-point pentagram (self-intersecting) — corner hotspot + path deviation. |
| `segments` | 4 parallel vertical lines — blank-jump leakage between disconnected strokes. |
| `circle` | Continuous curve, no real corners — path deviation + brightness uniformity. |
| `spiral` | Dense continuous curve — path deviation + brightness uniformity under high interior density. |

Since v6.04.1, `/api/calib-cam/start` accepts a `channel` field (default: **blue**, channel 3) instead of always drawing white. A mono camera can see the R/G/B beams smear apart or land at slightly different positions if the laser diodes aren't perfectly co-boresighted — measuring on one channel avoids that artifact entirely. `optimizeGalvo.py` drives this from `camPatternChannel` in `camConfig.json`.

## Workflow

Run `optimizeGalvo.py <command> --help` for any command's full description; the summaries below are the short version. Two flags apply across most commands: `--no-view` (disable the live camera preview window, e.g. for headless runs) and `--zoom {1,2,3}` (digital zoom on that window, live-adjustable with the `1`/`2`/`3` keys).

### 0. wizard

Interactive first-run setup — prompts for ESP32 base URL, camera index/resolution, exposure, DAC calibration range, and HTTP timeout, showing current/default values in brackets. Runs automatically the first time any command is used with no config file yet; run it directly later to change settings.

### 1. check

```bash
python optimizeGalvo.py check
```

GETs `/api/status` and prints firmware version, network info, and safety-interlock state. Opens no camera — run this first whenever something isn't working, to rule out a wrong base URL or a WiFi/mDNS problem before chasing camera or optics issues. Exits 1 on failure.

### 2. preview

```bash
python optimizeGalvo.py preview
```

Live grayscale feed with saturation %, peak pixel value, and measured fps overlaid. `+`/`-` adjust exposure live (auto-saved), `1`/`2`/`3` zoom, `s` saves a snapshot, `space` freezes the frame, `q` quits. Use this to physically aim/focus the camera and dial in exposure — visible beam trace, not blown out — before calibrating.

### 3. calibrate

```bash
python optimizeGalvo.py calibrate
```

Captures a dark background, projects `corners4`, detects the four dots, and solves the pixel→DAC homography, saving it (with the background) to `homography.npz`. Required once before `measure`/`optimize`/`diagnose`; re-run whenever the camera or projection surface moves. Saves a labeled snapshot marking which dot was identified as TL/TR/BR/BL — check it against the real physical layout if later measurements look rotated or mirrored.

### 4. measure

```bash
python optimizeGalvo.py measure --pattern square
```

Projects one pattern with currently-live parameters, captures, and prints path-deviation RMS, blank-leakage, corner hotspot, brightness non-uniformity, and the weighted cost. Requires `homography.npz`.

### 5. optimize

```bash
python optimizeGalvo.py optimize --profile Vector --trials 40 --apply
```

The main event. Queries the ESP32 for its optimizer profiles and preset membership, runs one Optuna study per selected profile against its `searchSpace.json` ranges, and prints a before/after report — every parameter marked changed, unchanged-not-searched, or unchanged-behind-a-disabled-gate. Each trial calls `/api/calib-cam/params` with candidate values and sums the cost across the profile's pattern(s).

- `--profile Vector,Smooth` or `--profile all` selects profiles directly; `--preset "Milky Way"` tunes whichever profile drives a named preset instead (errors out for Wireframe/Trails/Text — not camera-tunable, no camera pattern exists for them). Omit both for an interactive menu.
- Studies persist in SQLite (`--storage`, default `results/optuna_study.db`) under `--study-name` (default: the profile name) — Ctrl+C or a crash loses nothing, just re-run the same command to resume. `--fresh` starts over instead.
- `--apply` applies the winning values to the ESP32 and persists them via `/api/optimizer-save` without asking. **Without it, results only go to the JSON file** — see [Session Semantics](#session-semantics--nothing-sticks-until-you-apply-it).
- `space` pauses between trials, `q` aborts early (like Ctrl+C; completed trials are kept).

### 6. diagnose

```bash
python optimizeGalvo.py diagnose --profile all --autotune
```

Measures each selected profile's current live output (no overrides — a read, not a search) and classifies it: **OK**, a **geometry issue** (size/position off vs. ideal — points at galvo gain/offset drift or a moved camera, fix with the Calibration tab or re-running `calibrate`, not by retuning), or an **optimizer settings issue** (path deviation/leakage/hotspot/uniformity out of tolerance while geometry is clean — genuinely fixable by tuning). `--autotune` runs `optimize` automatically on anything flagged with a settings issue, with the same `--trials`/`--study-name`/`--storage`/`--apply` options.

### 7. autotune-camera

```bash
python optimizeGalvo.py autotune-camera --trials 30 --apply
```

Added in optimizeGalvo v2.4.0. Tunes the camera's own **capture** settings — exposure, gain, `binaryThreshold`, `accumFrames` — instead of firmware parameters, which are left exactly as currently live. Useful when `measure`/`diagnose` results look inconsistent for reasons that turn out to be the camera, not the beam: washed-out captures, blooming, background noise. Since v2.5.0, saturated pixels are flagged as their own metric (`saturationFrac`) — a global-shutter sensor blooms into neighboring pixels at saturation, which can otherwise inflate path-deviation/corner-hotspot readings with a camera artifact rather than a real scan problem; `diagnose` will suggest running this command instead of `optimize` when it detects that. On apply, updates `camConfig.json` and refreshes `homography.npz`'s stored background to match the new exposure/gain (background is exposure-dependent, so a stale one would corrupt every later diff-subtraction).

---

## How Scoring Works

Every measurement reduces to a single weighted cost (`costWeights` in `camConfig.json`):

| Metric | What it catches |
| --- | --- |
| `pathDeviationRms` | How far the traced beam deviates from the ideal geometry — corner dwell and interior density problems. |
| `blankLeakage` | Laser visible during a blank jump — insufficient hold-off or blanking overshoot. |
| `cornerHotspot` | Excess brightness pooling at a corner — too much dwell relative to the rest of the shape. |
| `brightnessNonUniformity` | Uneven brightness along a continuous curve — interior density or velocity-easing issues. |
| `saturationFrac` (v2.5.0+) | Fraction of the traced beam at raw sensor saturation — flags a camera-artifact-inflated reading rather than a real defect. |

`optimize` and `diagnose` share this cost function; `autotune-camera` adds `saturationFrac` and a background-brightness penalty on top, since capture-quality problems (washed-out frames) don't show up cleanly in the four geometry metrics above.

## Session Semantics — Nothing Sticks Until You Apply It

A calib-cam session's overrides are **RAM-only** — they never touch NVS on their own. Starting a session (`/api/calib-cam/start`) snapshots the target profile's current values; every override applies on top of that snapshot; and `/stop` (or an E-Stop trip, which force-stops the session from `pattern_engine::task()`) **restores the snapshot**, discarding every change. This is deliberate — an interrupted or aborted tuning run must never leave a normal preset's optimizer profile silently altered.

Practical upshot: `optimize --apply` (or `diagnose --autotune --apply`) is what makes a result permanent — it calls `/api/optimizer-live` with the winning values and `/api/optimizer-save` to persist them, before the session ends. Without `--apply`, an interactive run prompts you per profile; a non-interactive run (e.g. from a script or CI) applies nothing and the tuned values only exist in the `results/best_<profile>_<timestamp>.json` file.

## Safety

This tool projects real geometry through the real laser via the normal `calib_active` render path — every hardware safety interlock in [Chapter 1](01-introduction.md#safety-interlock-chain) still applies unchanged (E-Stop, scan-fail, watchdog, ARM). Running an unattended multi-hour `optimize` session does not relax any of the precautions in [Chapter 1's Safety section](01-introduction.md#safety--read-this-first) — beam containment and eye protection rules apply exactly as they do to any other armed session.

## Version History

| Version | Change |
| --- | --- |
| fw v6.03.0 | Initial `/api/calib-cam/*` API and the 6 camera patterns. |
| fw v6.04.1 | Patterns default to blue; `channel` field on `/api/calib-cam/start`. |
| fw v6.05.0 | Fixed closed shapes not reconnecting when a heavily-tuned-down `max_pts_per_frame` starved corner dwell — see [Chapter 5](05-optimizer.md#stage-4--corner-dwell). |
| optimizeGalvo v2.4.0 | Added `autotune-camera`. |
| optimizeGalvo v2.5.0 | Added `saturationFrac` blooming metric. |

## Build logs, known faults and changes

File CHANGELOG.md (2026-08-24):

# Changelog

All notable changes to GalvOS, newest first. Versions are `MAJOR.MINOR.PATCH`
(see [Chapter 3 — Version Bumps](docs/03-build-and-config.md#version-bumps)) and are
tagged in Git as `vX.Y.Z`. Patch releases are folded into their minor line.

The WebUI carries its own independent `UI_VERSION`; it is not tracked separately here.

---

## 6.8x — Introspection: task viewer, honest CPU load, render timing (2026-08-19 → 2026-08-24)

- **6.85.0** — `paceProducer()`'s post-render pacing delay is now render-cost-
  compensated instead of a blind `drain_ms * 1.25` added on top of whatever
  `generate()`/the transform pipeline/`pushFrame()` already took, every frame,
  in every render mode (Preset, Text, Paint, Curve, Calibration, legacy DMX).
  Root cause of a live-reported "micro stutter, not as fluid anymore" that
  predates Flow Mode: the ring drains in real time regardless, and
  `galvo_out.cpp`'s galvoTask replays the current frame from its start on
  underrun instead of blanking (deliberate anti-flicker design) — so any
  per-frame variance in render cost (cache hit vs. miss, preset-to-preset
  cost, a Core-0 preemption by a higher-priority WiFi/DMX/safety task) showed
  up as the beam visibly holding position for an extra beat, then jumping to
  catch up. Made proportionally more visible once v6.82.0/v6.83.0's pipeline
  cache drove cache-hit render cost toward zero without touching the
  multiplier — the "wasted" margin became a larger share of an already-smaller
  frame. Fix: a single `esp_timer_get_time()` timestamp at the top of
  `task()`'s loop is now threaded through every `paceProducer(n, ...)` call
  site; the delay is `max(0, drain_ms*1.25 - actualRenderUs)` instead of
  always the full `drain_ms*1.25` — a cheap frame still gets the full Core-0
  safety margin, an expensive one gets little or none, so the total producer
  period tracks the intended target instead of target-plus-render-cost.
  Hardware-verified: flashed via `/api/ota/upload`+`/api/reboot` (laser disarmed
  throughout, booted clean, `dac_ok`/`subsystems_ok` true), then armed on an
  animated preset — Andre confirms the motion is "deutlich besser" (noticeably
  smoother), the hold-then-jump is gone.
- **UI v1.28.0** (2026-08-24, no firmware bump) — Presets tab reorganized: Autoscale,
  Auto-Rotation and Kaleidoscope & Mirror are now collapsible `<details>` sections
  (matching Points-Only Mode and Flow Mode's existing pattern) instead of always-open
  inline blocks. Color moved out of the Global Controls card into its own card alongside
  it, with Color Animations nested underneath as a collapsible section. BPM Clock,
  Countdown Timer, Parameter Modulators, Bindings and Sequencer are collapsible too now.
  Pure `data/index.html` reshuffle — no id, endpoint, or behavior changes.
- **6.84** — Flow Mode: a new global render option (Presets tab sidebar, next to Points-Only
  Mode) that lights only a sliding window of the already-generated path — one or several,
  evenly spaced — instead of the whole geometry at once, giving a travelling "comet" trail.
  Segments (1–8), Length % (1–100 of the lit path), Speed (0–255 → 0.05–3.0 laps/s,
  point-count independent), Direction and a tail→head Fade are all live-parametrizable via
  `/api/preset-live`. Never re-samples or reorders points — only ever blanks more of them —
  so it rides the preset's/optimizer's exact existing point spacing and blank-jump plan
  verbatim: `n` never changes and no new galvo jump is introduced anywhere. Gated into the
  v6.82/v6.83 whole-pipeline output cache's eligibility check, since the trail phase advances
  every frame. UI v1.27.0. Build-verified only — no hardware pass this session.
- **Audit** (2026-08-22, no version bump) — Live re-verification of v6.75.0's three
  incidental findings, closing out `State_fix.md`'s backlog (now removed; full numbers moved
  into `docs/optimizer-range-audit-2026-08-17.md`). Two held up: fallback constants
  (`brightnessNonUniformity`, `offsetX/YUnits`) are flagged `valid`/NaN rather than silently
  returned, and `max_safe_kpps` is confirmed a pure, unenforced ILDA-derate formula — live
  reading `6.0` today, not the doc's stale `17.6` (pre-dates the `rated_kpps` 45→15
  migration). One didn't: `blankLeakage`'s anti-correlation doesn't reproduce — a new
  streak-sweep tool (`scripts/optimizeGalvo/streak.py`) agrees with the tool's own corridor
  mean to 3 decimals, both monotonic the right way now, likely because the original reading
  predates the later exposure/shutter fix. Loose end left behind: `blankLeakage` still
  carries a live `weight=2.0` in cost, contradicting v6.75.0's own "nothing load-bearing"
  commit claim — currently harmless only because today's measured direction happens to agree
  with reality. Also hand-verified `applyPpsScaling` at half/double the reference kpps
  against all 8 live profiles: the PPS-scaled bounds do **not** uniformly hold — Smooth is
  already over its density ceiling at the reference rate, and at double-rate 5 of 8 profiles
  blow past it with `max_step_units` dropping below its own floor; nothing re-clamps the
  effective value after scaling.
- **6.83** — Every Core-0 load figure this project had ever acted on was wrong. The CPU
  monitor counted FreeRTOS idle-hook *invocations* against a baseline captured once at
  startup — but stored that window's raw count as if it had been 500 ms, and it never
  was: the monitor starts at the top of `setup()` while the first measurement comes from
  the WebUI task, created only after the blocking Wi-Fi connect. Every reading afterwards
  was a function of how long boot happened to take. A second, independent flaw: idle-loop
  iteration cost is not constant, because it is served from the flash cache both cores
  share — measured 437 vs 869 invocations/ms in the *same* idle state. Replaced with the
  CPU cycle-counter delta between consecutive hook calls, i.e. elapsed idle time in
  absolute units, with no reference to calibrate. Verified on hardware against the same
  idle state: **73% → 1%**. The v6.71.1 Core-0 pacing fix still stands — the device
  really did go unreachable — but the percentages that framed it as "Core 0 is saturated
  at idle" were an artifact, and every Core-0 number recorded before this release should
  be re-measured rather than converted. `/api/tasks` now publishes `cpu.idle_pct0/1` so a
  load figure can be checked against its own measurement, plus a `render` block giving
  the Preset pipeline's per-frame cost split into generate / pipeline / push microseconds
  — turning "the pattern engine costs N% of Core 0" into an attributable number. With
  that instrument in hand: the whole-pipeline output cache's signature test moved ahead
  of `generate()`, since it never needed the geometry to decide. A cache hit had still
  been paying for two redundant 10 KB PSRAM copies; it now pushes straight out of the
  cache, 1172 µs → 501 µs per frame with byte-identical output. And Art-Net, Ether Dream
  and Helios turned out to poll their sockets at 200/500/500 Hz while switched *off* —
  their enable flags gated the data path but not the tasks, and the Helios flag was never
  read at all.
- **6.82** — Static presets stopped re-rendering what hadn't changed. The v6.81 geometry
  cache only skipped pattern generation; every downstream stage — colour animation,
  duplicator, mirror, kaleidoscope, points-only mode, the DMX-view transform, calibration
  — still walked the whole point buffer each frame on Core 0. A second cache now captures
  the finished frame and replays it verbatim while every input those stages read is
  unchanged. Deliberately narrow: it engages only for the six presets already proven
  phase-independent, with colour animation and all the symmetry effects off and the
  inverse filter inactive, and falls through byte-identically otherwise.
- **6.81** — A read-only Task Viewer moved into the Log tab, answering "what is actually
  running on Core 0" without a serial monitor: core, priority, state and free stack for
  every task, refreshed while the tab is open. It immediately earned its keep by catching
  a bug it was built to look for — the galvo output task is pinned to Core 1 at top
  priority and never yields, which is the same core Arduino runs `setup()` on, so every
  statement placed after it started had been silently unreachable since it was
  introduced. The SD auto-mount watcher was one of them and had likely never run.
- **6.80** — The Dashboard admits the ESP32 has a temperature too: a new `cpu_temp`
  field (`/api/state`) reads the SoC's internal die sensor, plotted alongside the
  DS18B20 probes on the Temperature History chart and shown as its own System card
  field. Buffer Fill and Wi-Fi RSSI each get their own scrolling history chart —
  previously only their instantaneous values were visible in the Telemetry card — with
  RSSI showing green/yellow/red good/medium/bad zone bands instead of raw dBm numbers.
  The six Dashboard charts are now laid out as an actual 3×2 grid, and the four
  single-metric ones (CPU Load, Galvo Output Rate, Buffer Fill, RSSI) grew a min/avg/max
  readout under them — skipped on the multi-series Temperature/Frame charts, where a
  blended min/avg/max across unrelated series wouldn't mean anything.

---

## 6.7x — Output rate autotune (2026-08-19)

- **6.79.1** — `points_per_sec` returned a wrapped garbage value after long polling gaps.
  `pointsPerSec()` did `(delta_points * 1000) / elapsed` in 32-bit, and its averaging
  window is not 1 s — nothing recomputes the counter on a timer, so the window is however
  long it has been since something last *read* it. With no poller (WebUI closed) that
  window grows without bound, and at ~45 kpps a gap over ~95 s overflows the multiply.
  Measured on this board: first reads after 100 s and 140 s of silence returned 2457 and
  14694 pps against a true 45355 — matching the wrapped arithmetic to within 0.1%, while
  30 s and 60 s gaps read clean. Not cosmetic: `optimizeGalvo` derives the camera shutter
  from this field, and a 4.8 kpps reading made it compute a 251.6 ms frame period for a
  pattern that takes 26.8 ms. Both this and `fps()` (same shape, overflow past ~40 h
  rather than 95 s — latent, but no reason for the two to differ) now use the
  `(uint64_t) … * 1000ULL` idiom `autotuneTrial()` already uses in the same file. This
  also restores the "`points_per_sec` vs `projection.kpps` is the one-line health check"
  note, which was unreliable whenever the WebUI had not been open.

- **6.79** — `galvo_rated_kpps` migrated 45 → the datasheet 15. Not cosmetic: community
  presets ship raw optimizer values with no anchor of their own and the firmware default
  anchor is 15, so every import was read with `r` 3× too large — density 3× low, accel
  ceiling 9× too permissive. The rescale factor has the output rate cancel out, making it
  an exact change of units (`raw_new = raw_old × k^e`, k=3) rather than a re-tune: zero
  values saturate their bounds and effective values are preserved to 1.25e-06 across all
  8 profiles. Snapshots and derivation in `docs/migrations/`. Two fixes shipped alongside,
  each broken alone: `text_renderer.cpp`'s per-glyph density constant was tied to the
  anchor via `1/ppsRatio()` (would have tripled text density into the "only ~8 chars
  render" bug — now anchored to a local `TEXT_DENSITY_REF_KPPS`, verified 763→714→585 lit
  points as output drops 45→30→20 kpps), and the exit-angle warning compared the sample
  clock against the mechanical ILDA derating and would have been pinned on permanently.
  Separately: **`/api/restore` never worked** — the handler ignored `index`/`total` and
  parsed each ~1.4 KB TCP chunk as a whole document, so every ~6 KB backup failed with
  "bad json", WebUI Restore button included. Now reassembles the body first. Found by
  trying to use it for this migration.

- **6.78** — Two defects behind "autotune finds no limit". (1) `galvoTask`'s tick pacer
  accumulated an unbounded deficit: when `period_us` is shorter than the loop body
  (~21.3 µs here, a ~46.9 kpps ceiling) the busy-wait never binds and `next_tick` falls
  behind wall-clock every iteration, so lowering the rate afterwards did nothing for
  60–90 s while the optimizer, producer pacing and inverse filter all assumed the new
  rate. Five copies replaced by one `paceTick()` clamping the deficit to a single
  period. (2) The autotune's overflow criterion could not see this at all —
  `paceProducer()` throttles the producer to ~80% of the *commanded* rate, so a short
  consumer and a short producer stay balanced (`buffer_fill` 14% at 60 kpps, same as at
  43). It now measures achieved output ticks against commanded and requires ≥98%.
  Hardware-verified: the sweep returns 45 kpps with `achieved_pps` 46954, matching an
  independent manual measurement. The device's existing 43 kpps setting delivers 100.0%
  of commanded and was correct all along.

- **6.77** — The Projection tab's sample-rate autotune stopped inventing its own answer.
  It seeded its binary-search ceiling from `galvo_rated_kpps` — the galvo's *mechanical*
  ILDA spec, unrelated to the MCU sample throughput it actually measures — so with a
  rated value raised above the datasheet figure it returned `rated - margin` without
  ever observing a single overflow, and with an honest one it could never propose
  anything above it. It now searches the full 12–60 kpps range independently and reports
  `ceiling_not_reached` when the range runs clean end to end, instead of dressing the
  range top up as a measurement. It also refuses to run at all (`no_load`) when the ring
  is not being fed — with the master dimmer at 0 the producer delivers 25 pts/s into a
  ring draining at tens of thousands, so overflow is structurally impossible and every
  trial passes at any rate. The inverse filter is now refreshed per trial rather than
  only at the end, so a sweep is no longer measured through a filter still configured
  for the pre-sweep rate. WebUI: the Output Sample Rate slider is no longer capped at
  the rated speed (oversampling above the rated point rate is normal — the mirror
  low-passes what it cannot follow), and the Projection tab spells out that the two
  numbers are independent.

---

## 6.6x — Correction stages, cleanup (2026-08-12 → 2026-08-14)

- **6.67** — Triage pass over `bugs01.md`'s backlog. Safety/UX: idle output (no Preset/Text/
  Paint/ILDA/live DMX active) now blanks the beam instead of drawing a full-brightness legacy
  circle; ILDA `/api/ilda/play` no longer blocks the async_tcp task for the whole SD read/parse
  (was timing out `/api/ilda/status` polls and hanging the UI), running the load on its own
  task instead. Correctness: animation phase now advances by wall-clock time instead of once
  per loop iteration (H-Line's Speed slider ran up to 2x its intended rate on sparse frames);
  Autoscale Mode's WebUI labels matched a never-implemented "Off/Fit/Fill" instead of the
  firmware's actual Pulse/Grow/Shrink enum; Wave-preset harmonics fed a post-wrap multiplied
  phase into `aang()` instead of their own call, snapping once per loop instead of looping
  cleanly; Starburst Party's 24 spokes went through 24 separate per-spoke budget checks instead
  of one batched call, silently dropping the back half of the burst once the frame budget ran
  out. UI: Mirror H/V checkboxes were permanently disabled in Kaleidoscope mode, the one mode
  their own click handler exists to switch out of; Auto-Rotation Speed range widened back to
  the shipped default; quick-angle buttons added for Rotation; H-Line gained an optional bounce
  mode (eases back down instead of snapping to the bottom every sweep); glyph outline text
  (Paint's Text tool) now clamps to the DAC range like the main Text tab already did, instead of
  rail-clamping into a smear at the canvas edge. Also: `scripts/optimizeGalvo/optimizeGalvo.py`
  maintenance pass (host-side tooling, no firmware dependency) — `measure-resonance` retries
  with a wider fine-sweep span instead of giving up on Q/`ring_damping_ratio`; `searchSpace.json`
  regenerates with sensible defaults when missing instead of erroring about a "shipped example"
  that never existed; `docs/06-camera-autotuning.md` gained the `calibrate-warp`/
  `measure-resonance`/`tune-dac-range` coverage it never had.
- **6.66** — Blank-jump emission de-duplicated into one shared helper; `/api/status` and
  `/api/state` now build their common fields from a single source so they cannot drift apart.
- **6.65** — Fixes: Particles/Starfield blank-jump window widened (dots stopped drawing
  connect-the-dots streaks), ILDA loader frame counting made consistent across both passes,
  dimmer pipeline no longer applies its scaling more than once, arming refuses while an OTA
  is in flight, Core 1 no longer blocks on SPI2, duplicate watchdog route removed.
- **6.64** — DMX BPM mapped 1:1 with **Beat-Stop** on channel value 0; Tap Tempo no longer
  expires mid-set; Points-Only fade defaults fixed; `/api/paint/set` no longer leaks state
  between clients.
- **6.62** — **Model-based inverse filter**: per-axis regularized deconvolution of the galvo's
  measured resonance, applied to every emitted point (`/api/inverse-filter/*`).
- **6.60** — Clip diagnostic: the firmware reports when output is being clipped rather than
  silently flattening corners.

## 6.5x — Warp, brightness, welding, SVG (2026-08-12)

- **6.59** — Per-segment colors for polygons and stars (`/api/seg_colors`).
- **6.58** — Curvature-adaptive resampling: point spacing follows the curve instead of
  distributing evenly along it.
- **6.57** — 2-opt refinement on top of the nearest-neighbour jump order.
- **6.56** — **Brightness compensation** grid: per-region RGB gain against throw-distance and
  angle falloff (`/api/brightness/*`).
- **6.55** — **Warp** grid (up to 5×5 keystone/surface correction, `/api/warp/*`) plus
  `outputScale`, a proportional pre-scale that keeps corners inside the galvo's linear range.
- **6.54** — **SVG import**: browser-side parsing and simplification into the Paint canvas,
  with SVG file storage on SD (`/api/svg/*`).
- **6.53** — **Laser Welding** effect: travelling torch head, fading afterglow, ballistic sparks,
  rendered from the Paint canvas (`/api/weld*`).
- **6.52** — Mirror mode no longer reflects into itself.
- **6.51** — Kaleidoscope reworked to a true dihedral fold-then-stamp.

## 6.4x — Optimizer refactor wave (2026-07-31 → 2026-08-12)

A systematic pass over `point_optimizer.cpp`, tracked as prompts P1–P23.

- **6.50** — ILDA frames get smooth landing behavior; optimizer comments brought in line with
  what the code actually does.
- **6.49** — Segment reorder (nearest-neighbour jump ordering); Pillar 2 stops treating every
  jump as the same length.
- **6.48** — Five copies of the blank-jump logic consolidated; straight lines no longer dim in
  the middle (endpoint dwell and edge shaping decoupled).
- **6.47** — Frame budget measured instead of estimated.
- **6.46** — Plan and emit stages share one description of the frame.
- **6.45** — Dead knobs removed: `min_segment_pts`, `speedT`, `lift` recoloring; corner severity
  computed once instead of six times.
- **6.44** — Per-frame context tracking; min/max pairs corrected; scratch buffer enlarged;
  PPS scaling extended to every density parameter; acceleration clamp works in both directions.
- **6.43** — Blank jumps land on target: ZV shaper tail extended, budget over-reservation fixed,
  Pillar 3 status published, zero-length jumps skipped.
- **6.42** — Optimizer telemetry (`/api/optimizer-stats`, Live Telemetry card).
- **6.41** — `/update` page rebuilt: firmware **and** filesystem OTA, real error reporting,
  progress bar, no auto-reboot, backup shortcut.

## 6.3x — WebUI rewrite and reorganization (2026-07-29 → 2026-07-31)

- **6.40** — ILDA file delete/rename/download from the browser.
- **6.39** — ILDA eviction and renaming; Helios USB stub removed for good.
- **6.38** — Color animations and Points-Only mode sync to the BPM clock.
- **6.37** — Temperature display unit (°C/°F/K), per-sensor names and offsets.
- **6.36** — Preset defaults and slider ranges brought in line with firmware behavior;
  per-category hover glyphs on preset tiles.
- **6.35** — Independent `UI_VERSION`; Dashboard field-grid layout; fixed a chart error that
  blanked the Dashboard for the first minutes after boot.
- **6.34** — Mobile safety controls: ARM and Master Dimmer always visible, 44 px touch targets,
  accessible status dots.
- **6.33** — Dashboard becomes status-only, Presets tab becomes the performance surface;
  pinned top bar; preset switching no longer flashes a streak.
- **6.32** — Full WebUI rewrite: three themes on a CSS token engine, responsive shell, 13 tabs.
- **6.30–6.31** — Spatial Noise (2D value-noise modulator type), Dotter (dot scatter), and
  optimizer jitter.
- **6.28–6.29** — Camera module (3D view targets) and Duplicator (grid/radial/spiral cloning);
  binding writes debounced off the network path.
- **6.27** — Modulator registry: modules self-register types and targets, UI discovers them.
- **6.26** — Layer engine removed (superseded by the modulators); sidebar reorganization.

## 6.2x — Beat, sequencer, modulation (2026-07-28)

- **6.25** — Presets tab consolidation; BPM Tap route fixed.
- **6.24** — Sequencer transitions no longer freeze modulator state.
- **6.23** — **Modulation engine**: 8 slots × 16 bindings (LFO, noise, envelope, step sequencer).
- **6.22** — **Preset Sequencer**: BPM-quantized set list with blank transitions; never
  auto-starts on boot.
- **6.21** — **Global BPM clock** (Manual / Tap / DMX).
- **6.20** — Network streams no longer contend with DMX for the ring buffer; Ether Dream
  buffer handling and client diagnostics fixed.
- **6.17** — First switchable WebUI themes.
- **6.16** — Per-protocol debug logging for every network input.
- **6.15** — Ether Dream no longer reports a permanent warm-up state.

## 6.1x — ILDA and SD (2026-07-27)

- **6.14** — Live ILDA speed/size parameters; standing SD auto-mount retry.
- **6.13** — ILDA playback passes through the affine transform and velocity clamp only.
- **6.12** — Oversized files greyed out against a PSRAM estimate; upload filenames sanitized.
- **6.11** — Playlist tab folded into ILDA/SD; per-file loading indicator.
- **6.10** — SD subfolder scanning; ILDA player master switch; load-loop yielding and real
  SD mutex enforcement.

## 6.0x — Network protocols, backup, camera tuning (2026-07-21 → 2026-07-26)

- **6.09** — SD tab play controls.
- **6.08** — **sACN/E1.31**, **OSC**, and **Helios network DAC** receivers, each individually
  enable-able.
- **6.07** — **Community Presets**: GitHub browser, on-device storage (20 presets), strict
  schema validation, versioned backup filenames.
- **6.06** — **Backup & Restore** of the full configuration as one JSON document.
- **6.05** — Corner dwell scales down to fit the frame budget (closed shapes always reconnect);
  text mode overhaul.
- **6.04** — ~120 KB of static scratch buffers moved from DRAM `.bss` to lazily-allocated PSRAM.
- **6.03** — **Camera-in-the-loop calibration API** (`/api/calib-cam/*`) and the host-side
  `optimizeGalvo.py` tool.
- **6.02** — DAC8562 SPI clock raised to 40 MHz.
- **6.00–6.01** — NVS partition grown to 256 KB; Wi-Fi scan rewritten against the IDF API;
  orientation/mirroring bugs fixed across text, fireworks, tree, and paint.

## 5.9x — SD card on its own bus (2026-07-21)

- **5.90** — **SD moved to an independent SPI3 bus** (GPIO5/6/1/42). Root cause of "the galvos
  go crazy when a card is inserted": Arduino's `SPIClass(HSPI)` binds to SPI3, so wiring SD onto
  SPI2's pins let it steal the DAC's clock and data lines through the GPIO matrix.

## 5.8x–5.89 — Optimizer, memory, WebUI groundwork (2026-07-18 → 2026-07-20)

- Memory owner registry and the WebUI Memory Viewer (`/api/meminfo`).
- Text optimizer profile; ring-buffer fill reporting fixed.
- Laser-on hold to suppress blank-jump entry strokes.
- Paint canvas scaled to the configured projection zone.
- Pinned header/safety banner; charts gained hover crosshairs and a time axis.

## 5.1x–5.8x — Feature build-out (2026-07-02 → 2026-07-17)

- Point optimizer stages: resample, velocity/acceleration clamps, PPS scaling, static-pattern
  cache, per-preset-class profiles, Smart Defaults, sample-rate autotune.
- Calibration suite: per-channel visibility thresholds, three-circle white balance,
  CIE 1931 perceptual LUT, calibration pattern library, projection zone editor.
- Paint by Finger, Points-Only mode, auto-scale, kaleidoscope, dynamic preset list,
  text renderer overhaul.
- Art-Net input with source-priority arbitration; thermal power reduction wired into fan control.

## 5.0x — The optimizer arrives (2026-06-20 → 2026-07-01)

- **Pillar 1** — adaptive, corner-aware point density.
- **Pillar 2** — distance-proportional, smoothstep-eased blank jumps.
- Color animation engine moved into firmware (DMX CH23–25); segment color mode.
- Raw SPI2 register access for DAC writes (~22 → 30 kpps).

## 4.5.9 — Initial public commit (2026-06-16)

First tracked version: ESP32-S3 firmware replacing the OEM controller, with DAC8562 galvo
output, DMX-512 input, the WebUI, and the hardware safety chain.

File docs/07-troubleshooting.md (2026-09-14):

# Chapter 7 — Troubleshooting

*Previous: [Chapter 6 — Camera-in-the-Loop Auto-Tuning](06-camera-autotuning.md)*

> Things go wrong. This chapter documents what they look like, why they happen, and what to do about them. The tables are kept terse on purpose — if you are here, you probably want the answer, not a lecture.

## Table of Contents

- [Before You Debug](#before-you-debug)
- [Reading the Serial Log](#reading-the-serial-log)
- [Boot & Connectivity Issues](#boot--connectivity-issues)
- [Galvo Issues](#galvo-issues)
- [Laser Issues](#laser-issues)
- [Color & Calibration Issues](#color--calibration-issues)
- [Optimizer & Pattern Quality Issues](#optimizer--pattern-quality-issues)
- [WebUI Issues](#webui-issues)
- [ILDA & SD Card Issues](#ilda--sd-card-issues)
- [Safety System Issues](#safety-system-issues)
- [Memory & Stability Issues](#memory--stability-issues)
- [Known Bugs & Limitations](#known-bugs--limitations)

---

## Before You Debug

A serial monitor attached to the ESP32 is your best friend. Open it before you power anything up:

```bash
pio device monitor
```

Default baud rate: **115200**. The monitor uses the `esp32_exception_decoder` filter, which decodes Guru Meditation addresses into file names and line numbers automatically.

The boot log tells you nearly everything: firmware version, chip ID, PSRAM size, free heap, Wi-Fi connection result, task start confirmations, and — if anything goes wrong — what failed and why. Read it before trying anything else.

**Key log messages to know:**

| Message | Meaning |
| --- | --- |
| `=== GalvOS Laser FW x.x.x ===` | Firmware started successfully |
| `Config loaded. DMX=x Hostname=x` | NVS config loaded OK |
| `WiFi connected: x.x.x.x (RSSI -xx dBm)` | STA mode connected |
| `WiFi timeout -- SoftAP 192.168.4.1` | Wi-Fi unreachable, fallback AP started (SSID/password also logged) |
| `Ring buffer overflow #N` | Pattern engine is generating frames faster than the ISR drains them — see [Optimizer Issues](#optimizer--pattern-quality-issues) |
| `TASK FAILED: name (Heap=N)` | A FreeRTOS task could not be created — internal heap exhausted at boot |
| `last_failsafe: reason` | Why the safety system refused to arm last time |
| `[heap] after patterns::init: N B free` | Internal DRAM available after startup; should be ≥30 KB |

---

## Reading the Serial Log

Log levels in GalvOS:

- `I` (INFO) — normal operation, printed in white/default
- `W` (WARN) — something unexpected but recoverable
- `E` (ERROR) — something failed; operation may be degraded

The WebUI Log tab (streaming over WebSocket) shows the same output. It auto-refreshes only when the Log tab is active.

If the ESP32 crashes with a Guru Meditation error, the serial monitor prints a back trace. With the `esp32_exception_decoder` filter active in PlatformIO, the addresses are decoded into source file names and line numbers. Copy the full crash output — it is the fastest path to finding the bug.

---

## Boot & Connectivity Issues

### No serial output at all

**Cause:** Wrong serial port, wrong baud rate, or USB cable is charge-only (no data lines).  
**Fix:** Verify you are using the UART USB port on the DevKitC-1 (labeled "UART", not "USB"). Try a different cable. Confirm `monitor_speed = 115200` in `platformio.ini`.

### Firmware boots but immediately restarts in a loop

**Cause A:** Heap exhausted during task creation.  
**Diagnosis:** Serial log shows `TASK FAILED: name (Heap=N)` with N near zero.  
**Fix:** Something is allocating on internal DRAM that should be in PSRAM. Check that `BOARD_HAS_PSRAM` is defined and that the N16R8 OPI PSRAM is detected (`PSRAM: 8388608` in boot log).

**Cause B:** Panic handler fired — laser turned off, `esp_restart` called.  
**Diagnosis:** Serial log shows `Guru Meditation` or `abort` before the restart.  
**Fix:** Decode the back trace with `esp32_exception_decoder`. The `last_failsafe` field in `/api/state` stores the reason in RTC memory across restarts.

### No Wi-Fi AP appears after first flash

**Cause:** the AP only starts after the Wi-Fi connect attempt times out — give it a few seconds. A missing LittleFS image does not prevent it.  
**Fix:** Use `pio run --target upload_all`, not just `upload`. Confirm the AP started in the serial log (`SoftAP '<ssid>' PW: '<password>'`) — the SSID is `Laser-XXXX`, not a fixed name.

### WebUI loads but shows "-- none --" everywhere

**Cause:** JavaScript running but API calls failing — server not yet ready, or a route is returning errors.  
**Diagnosis:** Open browser DevTools → Network tab. Look for failed `/api/state` calls.  
**Fix:** Wait 5–10 seconds after boot for all tasks to initialize. If still failing, check serial log for errors.

### mDNS hostname (`galvOS.local`) not resolving

**Cause:** mDNS not supported on some networks (corporate Wi-Fi, VPNs) or Windows without Bonjour.  
**Fix:** Use the IP address directly. Find it in the Dashboard → System card, or in the serial log: `WiFi connected: x.x.x.x`.

### Wi-Fi scan (Configuration tab) returns "error" or hangs

**Cause:** `WiFi.scanNetworks` on the Arduino core has several failure modes on the ESP32-S3 — a busy-bit that stays stuck after a mode switch, `WIFI_SCAN_FAILED` while STA is mid-(re)connect, or an async completion event that doesn't reliably fire under load.  
**Fix:** GalvOS calls `esp_wifi_scan_start`/`esp_wifi_scan_get_ap_records` directly instead of going through `WiFiScanClass`, retries up to 3× on any negative result code, and reports a distinct `"error"` status to the UI rather than silently looping. If a scan still fails repeatedly, check the serial log for `esp_err_to_name` plus internal-heap headroom — `esp_wifi_scan_start` needs a contiguous internal-DRAM block, so heap pressure (see [Memory & Stability Issues](#memory--stability-issues)) is a plausible root cause.  
**Note:** An AP-mode (SoftAP) scan returning 0 networks is a separate, unfixable ESP-IDF channel-lock limitation — enter the SSID manually instead.

### Wi-Fi drops and does not reconnect

**Cause:** The Wi-Fi watchdog task detects the drop and sets `s_wifi_services_started = false`. `setAutoReconnect(true)` handles reconnection automatically.  
**Diagnosis:** Serial log shows `WiFi dropped, will auto-reconnect`, followed by a reconnection or continued attempts.  
**Fix:** Usually self-resolves. If it does not, check signal strength (RSSI). Values worse than −75 dBm cause intermittent drops.

---

## Galvo Issues

### Galvos go crazy when SD card is inserted

**Cause:** the SD card is wired onto the DAC8562's SPI2 pins. Arduino's `SPIClass(HSPI)` binds to the SPI3 peripheral on the ESP32-S3, so an SD card wired to SPI2's pins steals the DAC's clock/data lines through the GPIO matrix whenever the card is actually accessed.
**Fix:** wire SD to its own bus — SCK=GPIO5, MOSI=GPIO6, MISO=GPIO1, CS=GPIO42 — with zero pin overlap with the DAC's SPI2 (GPIO10/11/12). This is what the firmware expects; see `include/pinmap.h`.

### Output is mirrored horizontally

**Fix:** Calibration tab → Invert X checkbox → Save calibration.

### Output is mirrored vertically

**Fix:** Calibration tab → Invert Y checkbox → Save calibration.

### Output is rotated 90°

**Cause:** X and Y galvo channels are wired in reverse.  
**Fix:** Calibration tab → Swap X/Y checkbox → Save calibration.

### Image is off-center

**Fix:** Calibration tab → X Offset / Y Offset sliders. Use the Crosshair calibration pattern as a reference. Save calibration.

### Image is too large or too small

**Fix:** Calibration tab → X Gain / Y Gain sliders (use "Linked" to keep aspect ratio). Or adjust the Size slider in Global Controls (Presets tab) per-session.

### Visible ringing / oscillation on blank jumps

**Cause:** The galvo mirror is oscillating at its natural mechanical resonance frequency after arriving at a new position.  
**Fix — Quick:** Increase `blank_samples` in the Optimizer tab. More settle ticks give the mirror more time to damp out.  
**Fix — Proper:** Measure `ring_freq_hz` and `ring_damping_ratio` with an oscilloscope (step response on the galvo feedback signal), then enable `ringing_comp_enabled`. See [Chapter 5 — ZV Ringing Compensation](05-optimizer.md#stage-8--zv-ringing-compensation-pillar-3).

### Corners look rounded or don't meet

**Cause A:** Not enough corner dwell points.  
**Fix:** Increase `max_corner_pts` in the Optimizer tab.

**Cause B:** `galvo_kpps` set too high for the scan angle. The galvo cannot settle at the corner before the next edge starts.  
**Fix:** Reduce `galvo_kpps` (Projection tab). Run the Autotune to find the safe maximum.

### Closed shape has a visible gap instead of reconnecting

**Cause:** At a heavily tuned-down `max_pts_per_frame`, corner dwell was treated as fixed overhead — only interior density was ever scaled back to fit the frame budget. On a many-vertex closed shape (Octagon and up, dense Lissajous/rose/trochoid curves, Concentric Rings), corner dwell alone could exceed what was left of the budget, and the point emitter silently stopped mid-shape — always cutting off the final edge and closing dwell first, which reads as "the shape doesn't close."  
**Fix:** The optimizer now scales `min_corner_pts`/`max_corner_pts` down together (floor: 1 point per vertex) whenever corner dwell alone doesn't fit the budget, trading corner sharpness for a guaranteed closed loop. This is automatic — no configuration needed. If you still see a gap on current firmware, `max_pts_per_frame` is too low even for 1 point per vertex; raise it in the Optimizer tab.

### Straight lines look curved

**Cause:** The galvo mirror is still settling from a blank jump when the first interior points of the edge are being drawn.  
**Fix:** Increase `blank_samples` and `min_blank_samples`. Ensure the smooth step blanking is active (it always is — but increasing the sample count gives it more travel time).

### Image flickers or strobes at high frame rates

**Cause:** Ring buffer overflow — the pattern engine is pushing frames faster than the ISR is draining them. Serial log: `Ring buffer overflow #N`.  
**Fix:** Reduce `opt_max_pts_per_frame` in the Optimizer tab (fewer points per frame = higher frame rate). The Autotune function in the Projection tab finds the highest safe kpps for the current pattern.

### DAC output stuck at 0x8000 (center)

**Cause A:** `gDebugNoHW = true` — No-HW mode is active, DAC writes are skipped.  
**Fix:** Configuration tab → Debug → No-HW Mode → disable → reboot.

**Cause B:** DAC8562 /CLR line held low.  
**Fix:** Verify `PIN_DAC_CLR_N` (GPIO13) pull-up to +5V (R_CLR 10 kΩ). Measure GPIO13 with a multimeter — it should read ~3.3V after boot.

---

## Laser Issues

### Laser fires at boot before ARM

**What is happening:** The fail-safe pull-ups (R_FSR/G/B, 10 kΩ → +3.3V) on GPIO7/8/21 hold the GPIOs HIGH during boot. This makes the 6N137 LEDs dark, which pulls the optocoupler outputs to +1.65V (HIGH) — which is "laser ON" for the MN-1M5AT active-HIGH driver.  
**Why this is expected:** This is the correct fail-safe behavior for the TTL signals. However, the laser power rail is controlled by PIN_LASER_ENABLE (GPIO38 → SSR1), which the safety system holds LOW until all conditions are satisfied. The laser cannot actually fire until `safety::allOk` returns true and the user presses ARM.  
**If the laser fires anyway:** The SSR1 is being energized before ARM. Check R_PD_EN (10 kΩ pull-down on GPIO38 → GND) is fitted. Measure GPIO38 at boot — it must be LOW before ARM.

### Laser does not turn on after ARM

**Cause A:** `master_dimmer = 0`.  
**Diagnosis:** Dashboard → Telemetry → Master Dimmer shows 0.  
**Fix:** Set Master Dimmer > 0 via the WebUI DMX override or DMX CH1. The guard `max(master_dimmer, ui_master_dimmer)` means both must be zero to produce no output.

**Cause B:** SSR1 not wired correctly, or relay contact open.  
**Diagnosis:** GPIO38 goes HIGH on ARM (measure with multimeter). If GPIO38 is HIGH but the laser power rail is still dead, the SSR or relay is the fault.  
**Fix:** Verify SSR1 wiring (IN+ from R_EN 1 kΩ to GPIO38, IN− to GND). Check SSR1 output contacts are in the laser power rail.

**Cause C:** `safety_override = false` and a safety condition is not met.  
**Diagnosis:** Dashboard → Safety Status shows a red LED. The `fault_reason` field shows which condition failed.  
**Fix:** Resolve the indicated condition (E-Stop wiring, scan-fail NE555 timing, watchdog heartbeat).

### One color channel missing

**Cause A:** 6N137 for that channel not powered or failed.  
**Diagnosis:** Measure +5V at that 6N137's VCC pin (Pin8) and VE pin (Pin7).  
**Fix:** Check power wiring to U_6N_R/G/B Pin8 and Pin7 → +5V_BUCK.

**Cause B:** Open circuit in the series resistor (R_R/G/B 220 Ω) or the GPIO → resistor trace.  
**Diagnosis:** Measure voltage across the 220 Ω resistor while that channel should be active.  
**Fix:** Re-solder or replace R_R/G/B.

**Cause C:** Firmware LEDC channel detached.  
**Diagnosis:** Check serial log for LEDC errors at boot.  
**Note:** `ledcAttachPin` is called once at `setup` — never per blank/un-blank cycle. If you see this error, something is calling it in a loop.

### Colors washed out or wrong after a color animation

**Cause:** The color animation left `col_override = true` with an unintended color. The `_stopGradient` function must send `col_override: false` to clear it.  
**Fix:** Presets tab → Global Controls → **↺ Reset Colors** button. This calls `resetColorOverride` which explicitly sends `col_override: false` to the firmware.

### Master Dimmer set to 100% but laser is very dim

**Cause:** `thresh_r/g/b` thresholds are set too high — the `mapVisibleRange` function is compressing the effective range.  
**Fix:** Run the visibility threshold calibration (Calibration tab → Start test beam → adjust Base R/G/B sliders). Alternatively, reduce the threshold values manually if you know your diodes' actual dead zone.

---

## Color & Calibration Issues

### Base color sliders in Calibration have no effect

**Cause:** The test beam bypass is not active. `mapVisibleRange(255, any_threshold)` always returns 255 — a full-brightness signal bypasses the threshold mapping.  
**Fix:** Press **▶ Start test beam** in the Calibration tab before adjusting threshold sliders. The test beam sends a logical level of ~1 (not 255), which goes through `mapVisibleRange` and is therefore controlled by the threshold value.

### Colors look blown out at mid-brightness (gamma issue)

**Cause A:** Gamma enabled on a laser driver that already applies its own gamma correction — double-gamma.  
**Fix:** Calibration tab → CIE 1931 Gamma → toggle off. Save calibration.

**Cause B:** `calib_patterns.cpp:colorOut` applies `applyGamma` before storing into `LaserPoint.r/g/b`, but `galvo_out.cpp:rgbWrite` applies it again.  
**Diagnosis:** This is a firmware bug pattern to be aware of when modifying calibration patterns. Each color value should go through gamma exactly once.

### Three-Circle Pattern colors do not match visually

**Cause:** White balance gains (gain_r/g/b) not calibrated for your laser module's actual power.  
**Fix A — Manual:** Calibration tab → Start Three Circle Pattern → adjust Gain R/G/B until all circles look equally bright.  
**Fix B — Auto:** Press **🪄 Auto White Balance** — computes gains from the power values in the Projection tab using V(λ) weighting. Only accurate if the power values (`power_r_mw`, `power_g_mw`, `power_b_mw`) are correct for your module.

### Calibration pattern looks wrong or produces incorrect output

**Cause:** Known issue with some calibration patterns. See [Known Issues](10-known-issues-and-todos.md).

---

## Optimizer & Pattern Quality Issues

### Pattern flickers

**Cause A:** Frame rate too low — `opt_max_pts_per_frame` too high.  
**Diagnosis:** Dashboard → Telemetry → Galvo Rate shows pps lower than expected. Serial log shows `Ring buffer overflow`.  
**Fix:** Reduce `opt_max_pts_per_frame` in the Optimizer tab until the overflow stops.

**Cause B:** Ring buffer underrun — pattern engine is generating frames too slowly (complex patterns at low kpps).  
**Diagnosis:** Serial log shows underrun messages.  
**Fix:** Reduce pattern complexity or increase `galvo_kpps`.

### No improvement in image quality above 1300 points per frame

**This is expected.** The known effective limit on the JY-15K-BL at 30 kpps is 1300 points per frame. Above this, the per-point time budget (33 µs) is the limiting factor, not the number of points. Setting `opt_max_pts_per_frame` above 1300 wastes frame budget without improving optical quality.

### Wireframe corners look bad (rounded or missing)

**Cause:** `buildWfChains` not called for this wireframe pattern. Isolated 2-vertex `PathSegment` entries prevent `has_incoming && has_outgoing` from ever being true, so corner dwell never fires.  
**Fix:** This is a firmware-side issue. When writing new 3D patterns, ensure `buildWfChains` is called to group edge pairs into proper chains before passing to the optimizer.

### Optimizer parameter changes have no effect

**Cause:** The pattern cache is serving a stale cached result. `gPatternCacheGen` was not incremented after the optimizer parameter change.  
**Diagnosis:** Change a non-optimizer parameter (e.g. speed), then change back — this forces a cache invalidation.  
**Expected behaviour:** Any optimizer parameter change via the WebUI automatically bumps `gPatternCacheGen`. If you are changing parameters directly in NVS without going through the WebUI, you may need to restart.

**Cause B:** A per-stage debug kill switch (Configuration → Debug → [Optimizer Debug — Kill Switches](04-ui-guide.md#optimizer-debug--kill-switches)) is forcing the exact stage you're tuning off, independent of the profile's own setting.  
**Diagnosis:** `GET /api/debug/optimizers` — any field `true` overrides that stage off regardless of the active profile.  
**Fix:** Flip the switch back, or `POST /api/debug/optimizers {"all": false}` to clear all of them. These are RAM-only and reset on reboot, but not mid-session — a switch left on from an earlier debugging pass survives until you clear it or power-cycle.

### PPS scaling produces unexpected densities

**Cause:** `galvo_rated_kpps` not set correctly for your galvo.  
**Fix:** Projection tab → set Galvo Rated Speed to your galvo's datasheet kpps. The optimizer uses the ratio `rated_kpps / galvo_kpps` to scale density. If rated_kpps is wrong, all scaled values will be wrong.

**Warning:** changing this value rescales every rate-dependent optimizer parameter's *effective* value at once — density by `1/r`, the velocity ceiling by `r`, the acceleration ceiling by `r²`. Simply editing `galvo_rated_kpps` therefore shifts how every existing profile behaves, sometimes drastically (a factor-of-3 correction, for instance, is a ×3 density swing and a ×9 acceleration-ceiling swing). If you need to correct a wrong rated value **without** invalidating existing tuning, transform the profiles' stored raw values by `k^e` (`k = rated_old / rated_new`, `e` per parameter as listed in [Chapter 5 — PPS Scaling](05-optimizer.md#pps-scaling)) instead of editing the field and re-tuning from scratch — the output rate cancels out of `k`, so this is an exact change of units, not a re-tune. See `docs/migrations/README.md` for a worked derivation. Note also that a community preset's `optimizer_profile` block ships raw values with no rated-kpps anchor of its own (see [Chapter 9](09-contributing.md#contributing-a-community-preset)) — it is interpreted against *your* device's rated value, so a mismatch there silently distorts every imported preset the same way.

### Output rate is far above the galvo's rated kpps

**Symptom:** the galvo is rated 15 kpps but `galvo_kpps` reads 30–45.

**This is not necessarily wrong.** The rated figure is a mechanical large-signal spec (ILDA test pattern at `ilda_test_angle`); `galvo_kpps` is the DAC sample clock. Running the sample clock above the rated point rate is oversampling — the mirror low-passes what it cannot follow, and the extra samples improve dwell granularity and interpolation smoothness. See the `kpps` entry in the [glossary](11-glossary.md). The Projection tab's Angular Configuration card shows an informational (non-warning) line stating the mechanical tracking rate at the current exit angle for reference — it is not a limit on the sample clock.

**What to check instead:** whether `galvo_rated_kpps` still holds the datasheet value — check `GET /api/projection`. If it has drifted from the datasheet figure, the PPS-scaling ratio `r = rated / output` is off, and the optimizer is silently running with the wrong effective density/velocity/acceleration ceilings for every profile.

**Note on the autotune button:** it measures the *controller's* sample-output throughput — how fast the ESP32 can actually deliver commanded points before it starts falling behind — not the galvo's mechanical rating; the two are unrelated quantities, and the ceiling it returns has no relationship to `galvo_rated_kpps`. It searches the full 12–60 kpps range and reports `ceiling_not_reached` if the whole range comes back clean. Start a real pattern (`master_dimmer` > 0) before running it — an idle/blanked output never overflows at any rate, so the search would report a false clean ceiling. `points_per_sec` (from `/api/state`) vs. `/api/projection`'s `kpps` is the one-line health check for whether the board is actually keeping up at the currently configured rate.

---

## WebUI Issues

### WebUI does not load (connection refused or timeout)

**Cause A:** LittleFS not flashed — `data/index.html` missing.  
**Fix:** Run `pio run --target upload_all`.

**Cause B:** the ESP32 fell back to AP mode and you are not connected to its `Laser-XXXX` network.  
**Fix:** Connect to the `Laser-XXXX` network (password in the serial log), then open `http://192.168.4.1`.

**Cause C:** mDNS not resolving `galvOS.local`.  
**Fix:** Use IP address directly (see Dashboard → System, or serial log).

### Preset grid is empty

**Cause:** `/api/presets` request failed — server busy or route error.  
**Fix:** Reload the tab. If persistently empty, check the serial log for errors on the `/api/presets` handler. The WebUI falls back to the static `STATIC_PRESET_DEFS` SVG lookup for thumbnails, but the grid itself requires the API.

### API returns 404 for `/api/calib-pattern/stop` or `/api/text/vertices`

**Cause:** Route registration order issue in ESPAsyncWebServer. These specific routes must be registered before any prefix-matching wildcard routes (`/api/calib-pattern/*`). This is a known architectural constraint — if you add new routes, keep this rule in mind.  
**Fix:** In `web_ui.cpp`, verify `/api/calib-pattern/stop` is registered before any prefix handler that would match `/api/calib-pattern/...`.

### Controls in the WebUI lag or don't respond

**Cause A:** Core 0 CPU load too high — requests are queueing behind the render pipeline.  
**Diagnosis:** Dashboard → CPU Load graph shows Core 0 sustained near or above 90%. Confirm it is real before acting on it: `GET /api/tasks` reports `cpu.idle_pct0` (the raw measurement the percentage is derived from) and a `render` block giving the per-frame cost of the pattern pipeline split by stage. Core-0 cost of rendering is `render.total_us × fps`; if that does not account for most of the load, the pattern engine is not what is loading the core.  
**Fix:** Reduce pattern complexity or close extra browser tabs connected to the device. Presets on the static allow-list are served from a whole-frame output cache and cost roughly an order of magnitude less than one that regenerates every frame (`render.cache_hits` vs `render.frames` shows whether the cache is engaging).

> **On firmware older than 6.83.0 this graph could not be trusted.** Its baseline was captured over the whole boot window and then scaled as if it were 500 ms, so the reading reflected how long boot took rather than actual load: an idle Core 0 reported ~73%, and the true 0–100% range was compressed into roughly 73–100%. If you are chasing "Core 0 is at 90%" on an older build, update first — there may be nothing to chase.

**Cause B:** Wi-Fi interference or weak signal causing packet loss.  
**Diagnosis:** Dashboard → System → WiFi Signal weaker than −70 dBm.  
**Fix:** Move ESP32 or access point closer together, or switch Wi-Fi channels.

### Laser show software connects but times out / desyncs (Ether Dream)

**Diagnosis:** enable the Ether Dream **Debug Log** toggle (Configuration → Control Interfaces). It logs raw command bytes and response timing to the Log tab, which is usually enough to tell "the client never sent anything" apart from "the client is waiting for a response it did not get".  
**Fix:** check that the Ether Dream interface is enabled at all, that only one client is connected, and that the client is not pacing off a larger point buffer than GalvOS advertises. `scripts/test_protocols.py` streams test frames from a PC for a known-good comparison.

---

## ILDA & SD Card Issues

### SD card causes galvo malfunction

**Cause:** the SD card is wired onto the DAC8562's SPI2 pins — see [Galvos go crazy when SD card is inserted](#galvos-go-crazy-when-sd-card-is-inserted) above.  
**Fix:** rewire SD to SPI3 (SCK=GPIO5, MOSI=GPIO6, MISO=GPIO1, CS=GPIO42).

### ILDA files not listed in the ILDA tab

**Cause A:** SD card not formatted as FAT32.  
**Fix:** Format the card as FAT32 (not exFAT, not NTFS). Maximum 40 `.ild` files indexed.

**Cause B:** SD card speed class insufficient.  
**Fix:** Use Class 10 UHS-I minimum. Class 4 cards are incompatible with reliable SPI access at DAC-sharing speeds.

**Note:** the card auto-mounts on a standing 5-second retry — a card inserted after boot gets picked up automatically. If the list stays empty, press **Rescan** in the ILDA/SD tab and check the SD status line for an error message.

### `task_wdt` reset while loading a big ILDA file

**Cause:** a genuinely slow card. Real SD cards can stall a single read for seconds during internal housekeeping, and a large file means many of those reads.  
**Fix:** loads yield on a wall-clock schedule and the task watchdog timeout is 15 s to accommodate such stalls, so a healthy card should not trip this — one that still does is failing or too slow (use Class 10 UHS-I). This task-watchdog timeout is a software recovery setting, not a qualified maximum laser-shutdown time. In the current V2 design, E-stop status is evaluated by firmware and GPIO38 controls the NE555 reset input; firmware-independent shutdown has not been established. See the [shutdown-boundary review](../hardware/reviews/2026-09-14-shutdown-boundary.md).

### ILDA playback stops by itself after a moment

**Cause:** a live DMX/Art-Net/sACN source is holding the ILDA-select channel (CH17) at 0, which means "stop". That channel only drives playback while such a source is actually present, so this needs a real console connected.  
**Fix:** set CH17 to the file you want, or disable the interface while working from the WebUI. Also check the ILDA Player's **Enabled** master switch hasn't been turned off.

---

## Safety System Issues

### System refuses to ARM — no obvious reason

**Diagnosis:** Dashboard → Safety Status card → `fault_reason` text line. Also check `last_failsafe` in `/api/state` JSON, which survives restarts and shows the last hardware-level shutdown reason.

**Common conditions and fixes:**

| Fault reason | Cause | Fix |
| --- | --- | --- |
| `estop` | E-Stop circuit open | Check J_ESTOP wiring. Pin1 must be pulled to +3.3V via R_ESTOP (10 kΩ). Shorting Pin2 to Pin1 disables E-Stop. |
| `scanfail` | NE555 scan-fail timer timed out | DAC must be producing output on VOUTA for the scan-fail NE555 (U11) to be triggered. Starts a preset before arming. Also check C_T/R_T values on U11. |
| `watchdog` | NE555 hardware watchdog timeout | GPIO14 heartbeat pulse from firmware not arriving at U12 TRIG. Check R_HB (1 kΩ) and NE555 U12 wiring. |
| `thermal` | Temperature above shutdown threshold | Check temperature sensors in Thermal tab. Default shutdown at 70°C. |
| `user` | User has not pressed ARM | Press the ARM button on the Dashboard. |

### Laser cuts out mid-operation

**Cause A:** Hardware watchdog timeout — firmware loop exceeded `watchdog_period_ms`.  
**Diagnosis:** Serial log shows watchdog-related messages. `last_failsafe` in RTC memory.  
**Fix:** Usually caused by a hang on Core 0 (Wi-Fi, heavy JSON serialization). Reduce WebUI polling frequency if you have custom integrations. Check for memory allocation failures.

**Cause B:** Temperature exceeded `temp_shutdown_c` (default 70°C).  
**Diagnosis:** Dashboard → Temperature History chart.  
**Fix:** Check fan operation. Verify thermal paste on laser diode module. Reduce `temp_shutdown_c` threshold if your setup runs hotter than expected for a softer warning margin.

**Cause C:** E-Stop button physically pressed or J_ESTOP connector loose.  
**Fix:** Verify E-Stop connector is seated. Check R_ESTOP (10 kΩ) pull-up is present.

### Scan-fail fires spuriously

**Cause:** NE555 U11 timing too aggressive for the configured kpps. At very low kpps, DAC updates are infrequent and the AC coupling (C_AC 100 nF) may not trigger the NE555 TRIG pin reliably.  
**Fix:** Increase `scanfail_timeout_ms` in the Configuration tab. Or increase `galvo_kpps` so DAC output is more frequent.

---

## Memory & Stability Issues

### Crash on boot — `Guru Meditation Error: Core 0 panic'ed`

**Most common cause:** Internal DRAM heap exhaustion during task creation or large allocation.

**Diagnosis:** Boot log line `[heap] after patterns::init: N B free`. Should be ≥ 30,000 bytes. If N < 10,000, something is allocating on DRAM that should be in PSRAM.

**Allocation rules:**

- Buffers > 16 KB → `ps_malloc` or `heap_caps_malloc(MALLOC_CAP_SPIRAM)`
- All `JsonDocument` instances → `JsonDocument doc(&jsonAllocator)` (uses `SpiRamAllocator`)
- API responses → `sendJsonPsram` (chunked, PSRAM buffer)

**Fix:** If you have added code that allocates large buffers, move them to PSRAM.

### `heap_critical_bytes` threshold triggered restart

**What happens:** If the largest free block of internal DRAM falls below `heap_critical_bytes` (default 6144 bytes), the firmware calls `esp_restart`. This prevents the system from reaching a state where even small allocations fail and cause undefined behavior.

**Diagnosis:** Serial log shows a restart with no Guru Meditation. Check `last_failsafe`.

**Fix A:** If this is triggered by normal operation, the `heap_critical_bytes` threshold may be set too conservatively for your configuration. Increase it slightly with caution.  
**Fix B:** If this is triggered by a specific action (opening a tab, loading a preset), that action is causing an unexpected internal DRAM allocation. Profile with the Log tab open.

### PSRAM not detected

**Symptom:** `PSRAM: 0` in the boot log. All PSRAM allocations fail silently.  
**Cause A:** Wrong board variant — must be N16R8, not N8R8 or no-PSRAM variant.  
**Cause B:** `board_build.psram_type = octal` or `board_build.arduino.memory_type = qio_opi` missing from `platformio.ini`.  
**Fix:** Verify `platformio.ini` settings. Verify the physical chip marking on the ESP32 module reads `N16R8`.

---

## Known Bugs & Limitations

A quick-reference index of open issues documented in [Chapter 10](10-known-issues-and-todos.md):

| Issue | Impact | Workaround |
| --- | --- | --- |
| Calibration channel selector not working | Minor | Calibrate with RGB combined |
| ILDA Standard Test Pattern bad output | Minor | Use Crosshair/Grid patterns instead |

---

*Next: [Chapter 8 — API Reference](08-api-reference.md)*

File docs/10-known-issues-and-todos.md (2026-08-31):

# Chapter 10 — Known Issues & Todos

*Previous: [Chapter 9 — Contributing](09-contributing.md)*

> This is an honest list. Every project has rough edges — GalvOS more than most, because it is a one-person hardware/firmware/UI project that started as a dimmer fix and grew considerably beyond that. Nothing here is hidden. If you run into one of these, you are not doing it wrong.

## Table of Contents

- [Critical Issues](#critical-issues)
- [Hardware Issues](#hardware-issues)
- [Pattern Issues](#pattern-issues)
- [Text Mode Issues](#text-mode-issues)
- [Calibration Issues](#calibration-issues)
- [UI Issues](#ui-issues)
- [Build & Tooling Issues](#build--tooling-issues)
- [Planned Features](#planned-features)
- [Contributing a Fix](#contributing-a-fix)

---

## Critical Issues

These affect core functionality and should be resolved before relying on those features in production.

### `safety_override` bypasses E-Stop and watchdog, not just scanfail

**Status:** Open — confirmed live, 2026-08-24
**Detail:** `.claude/CLAUDE.md`'s safety rules state `safety_override` "should NOT bypass
E-Stop, watchdog, or arming — only scanfail". The actual gate in `safety.cpp`'s `allOk()`
does not match that:

```cpp
bool allOk() {
    if (gConfig.safety_override) {
        return s_user_arm_request;  // bypass HW/watchdog/subsystem checks
    }
    return gState.estop_ok.load() &&
           gState.scanfail_ok.load() &&
           watchdogOk() &&
           subsystemsOk() &&
           s_user_arm_request;
}
```

With `safety_override` on, `estop_ok`, `scanfail_ok`, `watchdogOk()`, and `subsystemsOk()` are
all skipped — the comment even says so. Confirmed live: with the HW watchdog heartbeat
(GPIO14) not satisfied (`watchdog_ok:false`), arming failed normally, but flipping
`safety_override` armed the laser anyway (`laser_armed:true`) while `watchdog_ok` stayed
`false`. Whether E-Stop is also bypassable this way was not independently tested live (no
reason to trigger E-Stop just to check), but the code path is unconditional — it reads
`estop_ok` the same way as the other three, so there is no reason to expect it survives when
the others don't. Reconcile the code with the documented intent (scanfail-only bypass), or
update the documented intent if the wider bypass is actually deliberate.

---

## Hardware Issues

### Fan Tacho Inputs Not Read

**Status:** Open
**Detail:** `PIN_FAN1_TACH` (GPIO2) and `PIN_FAN2_TACH` (GPIO9) are wired through 4.7 kΩ pull-ups on the board, but no firmware reads them. There is no RPM readout and no stalled-fan detection — thermal safety relies entirely on the DS18B20 sensors.

### OPA4134 Gain Deviation

**Status:** Known, compensated in firmware  
**Detail:** The OPA4134 feedback resistors R2/R4 are 22 kΩ instead of the theoretical 10 kΩ, resulting in a gain of 2.2× rather than 2.0×. This means the full DAC swing would produce slightly more than ±5V at the galvo input. Compensated via `dac_limit_min`/`dac_limit_max` in `RuntimeConfig` (default: 0x0666..0xF999, ≈95% of full range). No action required unless you replace the resistors.

### Galvo driver board (vendor, JY-15K-BL) has marginal current-loop phase margin

**Status:** Open — confirmed by bench test, 2026-08-25  
**Detail:** Probing the X-axis coil leads directly (identified via resistance mapping on the
galvo's 7-pin connector: pin 1 red ↔ pin 4, 1.82 Ω — the only low-resistance pair, all other
pin combinations read MΩ/open) makes the galvo oscillate erratically. This reproduced with a
battery-powered, fully isolated handheld scope (Zoyi) — ruling out ground-loop/earth-reference
coupling as the cause — and persisted even with a 10:1 probe and a short spring ground tip,
i.e. with probe-added capacitance minimized as far as available equipment allows. That points
to the driver board's internal current-feedback loop having very little phase margin: even a
few pF of added load at the coil output is enough to tip it into instability.

Practical fallout:

- Cable/connector capacitance between the driver board and the galvo coil is not just a
  measurement inconvenience — it is plausibly part of the system's real stability margin.
  Longer or higher-capacitance wiring there could matter for actual operation, not only for
  probing it.
- Some fraction of the galvo ringing the point-optimizer compensates for
  ([`docs/05-optimizer.md`](05-optimizer.md), ringing/settling stages) may be electrical
  (driver loop) rather than purely mechanical (galvo resonance). The optimizer currently
  treats ringing as a mechanical/geometric problem to solve via dwell time and point density;
  it has no model for driver-loop-induced ringing and no way to distinguish the two sources
  from the pattern-generation side.
- The driver board is a sealed third-party module (not GalvOS firmware/hardware scope), so
  there is no fix available here beyond documenting it and being conservative about coil-side
  wiring changes.

No firmware action taken. Filed for awareness and as a possible lead if ringing compensation
tuning stalls on the mechanical-only model.

---

## Pattern Issues

### Raising the dimmer with no preset renders the legacy DMX pattern

**Status:** Open  
**Detail:** `pattern_engine.cpp`'s `legacyDmxActive` counts `gState.ui_override` as
"a controller is driving the DMX channels", so turning the master dimmer up from the
WebUI with **no preset selected** runs the legacy DMX emulation — `genPattern()` plus
the full transform/calibration/push path — every frame. Measured at 16–24% of Core 0
for a mode the user has switched off. But `ui_override` means "WebUI takes priority
over DMX", not "render the legacy DMX emulation"; `gOverride.active` and the real
DMX/Art-Net/sACN receivers already cover the cases where legacy rendering is wanted.
Dropping `ui_override` from that condition looks correct but is a user-visible
behaviour change, so it is filed rather than taken.

### Optimizer dominates the per-frame cost of any uncached preset

**Status:** Open — the next place Core-0 work belongs  
**Detail:** With per-stage render timing now available
([`/api/tasks`](08-api-reference.md#get-apitasks) → `render`), roughly three quarters
of every frame that misses the pipeline output cache sits inside `generate_us`, i.e.
in `optimizer::optimize()` — 5942 µs of a 7936 µs frame for Circle, measured at
44 kpps. The stages around it barely move between presets (`pipeline_us` ~1.9 ms,
`push_us` ~0.3 ms). The whole-frame cache only covers the six presets on
`presets::isStaticPreset()`'s explicit allow-list, so everything else pays this every
frame.

### Blank/unblank LEDC hold-tick margin unverified at high point rates

**Status:** Open — investigated 2026-08-26, inconclusive
**Detail:** `galvo_out.cpp:56-74` documents LEDC's own turn-on/turn-off latency (up to
2 PWM periods, ~40µs) and compensates with `LASER_ON_HOLD_TICKS`/`LASER_OFF_HOLD_TICKS`
(2 output ticks each), holding the DAC or the laser output steady around a blank
transition so LEDC has time to catch up before the galvo moves again. At the point rate
measured live this session (~43.5-45kpps, ~23µs/point), 2 ticks ≈ 46µs — a positive but
thin margin over the documented ~40µs latency, and it only gets thinner as point rate
climbs toward the ~46.9kpps output-rate ceiling.

A same-session attempt to verify this electrically (SPI + laser-TTL capture during a
real running preset) found evidence-shaped data — a 53-sample blanked stretch with two
single-frame "laser on" blips in the middle of it — but the test preset (Grid 3x3)
turned out to have real per-point behavior richer than a simple lit→blank→lit model
(a multi-tick dwell-and-relight at line junctions), making it impossible to distinguish
"intentional corner behavior" from "the margin is too thin" from electrical data alone.
See [`docs/sigrok-capture-tool.md`](sigrok-capture-tool.md)'s "Investigation: RGB
blanking-edge alignment" section for the full writeup and two concrete next steps
(a simpler two-shape preset, or temporary firmware logging of the intended per-point
blank flag).

### Curves backend is now dead code (WebUI card removed)

**Status:** Open — cleanup TODO  
**Detail:** The "∿ Curves" WebUI card (live parametric curve generator, distinct from the
"Curves" preset category which stays) was removed from `data/index.html` — no UI can reach it
anymore. `src/patterns/curve_patterns.cpp/.h`, the `pattern_engine.cpp` integration, and the
`/api/curves` GET/POST routes in `src/net/web_ui.cpp` were intentionally left in place for this
pass and are now unreferenced from the frontend. Remove them in a follow-up firmware cleanup.

---

## Text Mode Issues

None known at least...

---

## Calibration Issues

### Several Calibration Patterns Need Fixing

**Status:** Open  
**Detail:** A subset of calibration patterns produce incorrect or unexpected output. Specific patterns affected are under investigation.

### Channel Parameter Not Working

**Status:** Open  
**Detail:** The per-channel selector in the calibration flow does not correctly isolate individual channels in all cases.

### ILDA Standard Test Pattern — Incorrect Output

**Status:** Open
**Symptom:** The ILDA standard test pattern (ITC Rev.002 1995, used to verify galvo linearity and speed) does not render correctly, which makes it unusable as a calibration reference. Use the Crosshair and Grid patterns from the Pattern Library instead until this is fixed.

---

## UI Issues

### Disabled interfaces still hold their listening socket

**Status:** Partly fixed in 6.83.0; the remaining half is by design
**Detail:** OSC, sACN, Helios network DAC, Art-Net and Ether Dream each have an
enable/disable checkbox in Config tab → "Control Interfaces", plus a per-protocol Debug
Log toggle (DMX included). A disabled interface ignores received data instead of acting
on it, and its listening socket stays open until the next reboot. Only DMX has no enable
toggle — it is a hardware UART receiver with no radio/CPU cost worth toggling.

Until 6.83.0 those checkboxes gated only the *data path*: the receiver tasks were
created unconditionally and kept polling regardless — Helios and Ether Dream at 500 Hz
each, Art-Net at 200 Hz — while Ether Dream also went on broadcasting a discovery beacon
every second, advertising itself on the network and accepting TCP clients whose frames
were then silently dropped. `helios_net_enabled` was not read anywhere at all. Each task
now re-checks its flag on a 250 ms tick and skips the socket work entirely, hanging up
any attached client; the flag still takes effect without a reboot. What remains is only
the open listen socket itself, which costs nothing to hold.

### Telemetry "Source" label mismatch

**Status:** Open  
**Detail:** The Dashboard Telemetry card maps `state.source` through the array `['DMX','ArtNet','EtherDream','Helios','OSC','sACN','Internal']`, but the firmware's `ControlSource` enum is `0=none, 1=DMX, 2=ArtNet, 3=EtherDream, 4=Helios, 5=Internal, 6=WebUI, 7=sACN, 8=OSC` — so e.g. an active DMX source (1) displays as "ArtNet" and WebUI (6) displays as "Internal". One-line fix in `data/index.html` (`dash-source` handler).

### Inverse filter has no UI

**Status:** Open
**Detail:** The per-axis galvo deconvolution (`/api/inverse-filter/*`) is fully implemented in firmware and persisted to NVS, but there is no card for it anywhere in the WebUI — it can currently only be measured and configured over the REST API. A panel next to Ringing Compensation on the Optimizer tab is the obvious home.

### Hosted UI simulator drifts from the device UI

**Status:** Open
**Detail:** `docs/index.html` (served at [www.galvos.de](https://www.galvos.de)) is a standalone browser simulation of the WebUI, maintained by hand. It is not built from `data/index.html`, so it lags behind whenever the real UI changes.

---

## Build & Tooling Issues

### `sigrokCapture.py`: LA1010 capture duration collapses with >3 channels; two live-session gotchas

**Status:** Open — documented, worked around, not fixed
**Detail:** Confirmed live 2026-08-26, three separate findings while probing GPIO7/8/21
alongside the DAC SPI bus (see [`docs/sigrok-capture-tool.md`](sigrok-capture-tool.md)
for full detail):

- `kingst-la2016`'s `--time` delivers a real captured window that shrinks hard as more
  channels are enabled — 3 channels (SCLK/DIN/SYNC) got ~84% of a requested 50ms, adding
  one more channel dropped that to ~9%, adding all three RGB channels dropped it to ~2%
  (~1ms), independent of what duration is actually requested. `--samples` doesn't avoid
  this — it hangs outright with any laser-TTL channel enabled, at any sample count tried.
- `gState.calib_thresh_test` (left `true` from an earlier session) silently overrides
  `/api/debug/hw` — `galvo_out.cpp`'s output task checks it before `s_hw_debug_active`,
  forcing `writeDAC8562XY(0x8000, 0x8000)` regardless of debug x/y, with no indication
  anywhere in `/api/state`/`/api/status` that it's the actual cause.
- `/api/debug/hw`'s `x` field looks sign-inverted (`x:3000` and `x:-3000` both produced
  the DAC code for `-3000`) — not investigated further.

No firmware or tool changes made yet; filed as a heads-up for the next person using
`sigrokCapture.py` against RGB TTL lines or `/api/debug/hw`.

### Host regression suite cannot be run

**Status:** Open  
**Detail:** `platformio.ini` defines only the `esp32-s3-devkitc-1` environment, so
`pio test -e native` — the host-side optimizer contract tests under
`test/test_optimizer/` — has no environment to run in. The tests are still in the tree.
Restore a `native` env before the next optimizer change, which is exactly the kind of
work they exist to guard.

---

## Planned Features

These are features that are designed and intended, but not yet implemented.

### Control Interfaces

| Interface | Status | Notes |
| --- | --- | --- |
| Ether Dream (TCP) | ✅ Complete | Compatible with QLC+, Pangolin, LaserBoy, Shownet |
| DMX512 (MAX485) | ✅ Complete | Hardware RX-only |
| Art-Net (UDP) | ✅ Complete | DMX over IP |
| Helios DAC (network) | ✅ Complete | `src/net/helios_net.cpp` — custom TCP framing (5-byte header + 7-byte points), not the official USB protocol; wired through the live optimizer transform + frame-budget clamp like the other render paths |
| Helios DAC (USB) | ❌ Dropped | Not planned — TinyUSB vendor-class stub removed; USB-CDC conflict (Serial debug vs. Vendor-Class on same OTG controller) made it not worth pursuing |
| OSC (Open Sound Control) | ✅ Complete | `src/net/osc_in.cpp` — UDP port 9000, OSC 1.0 (no bundles); `/galvos/preset`, `/galvos/color`, `/galvos/speed`, `/galvos/brightness`, `/galvos/enable` |
| IDN (ILDA Digital Network) | ❌ Planned | UDP port 7255; discrete frame mode only (wave mode out of scope); requires IDN-Hello discovery + IDN-Stream frame parser |
| sACN / E1.31 | ✅ Complete | `src/net/sacn_in.cpp` — UDP multicast 239.255.0.1:5568, universe 1 only; lowest priority of the three DMX-shaped sources (Art-Net and DMX512 both win over it) |

### Multi-Controller

| Feature | Status | Notes |
| --- | --- | --- |
| ESP-NOW Sync | ❌ Planned | Peer-to-peer frame sync over WiFi hardware; ~1–2 ms latency; no extra hardware required; Master broadcasts frame counter + preset ID |
| ArtNet Master Mode | ❌ Planned | GalvOS as ArtNet sender; enables sync via existing show software (Pangolin, QLC+) |

### Stand-alone & Integration

| Feature | Status | Notes |
| --- | --- | --- |
| Autostart Preset | ❌ Planned | Persist last active preset in NVS; replay on boot without WebUI interaction |
| ILDA Output Header | ❌ Planned | Expose DAC X/Y + RGB TTL on standard ILDA 15-pin D-Sub; enables show software control without Art-Net |

---

## Contributing a Fix

If you fix one of the issues above, please see [Chapter 9 — Contributing](09-contributing.md) for the patch workflow and commit message format.

When submitting a fix for a known issue, reference the issue name from this chapter in your commit message body:

```text
fix: map Telemetry source labels to the real ControlSource enum

The Dashboard label array skipped SRC_NONE and SRC_WEBUI, so DMX
displayed as ArtNet and WebUI as Internal.
Resolves: "Telemetry \"Source\" label mismatch" (docs/10-known-issues-and-todos.md)
```

---

*Next: [Chapter 11 — Glossary & Terminology](11-glossary.md)*

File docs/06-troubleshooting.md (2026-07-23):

# Chapter 6 — Troubleshooting

> Things go wrong. This chapter documents what they look like, why they happen, and what to do about them. The tables are kept terse on purpose — if you are here, you probably want the answer, not a lecture.

## Table of Contents

- [Before You Debug](#before-you-debug)
- [Reading the Serial Log](#reading-the-serial-log)
- [Boot & Connectivity Issues](#boot--connectivity-issues)
- [Galvo Issues](#galvo-issues)
- [Laser Issues](#laser-issues)
- [Color & Calibration Issues](#color--calibration-issues)
- [Optimizer & Pattern Quality Issues](#optimizer--pattern-quality-issues)
- [WebUI Issues](#webui-issues)
- [ILDA & SD Card Issues](#ilda--sd-card-issues)
- [Safety System Issues](#safety-system-issues)
- [Memory & Stability Issues](#memory--stability-issues)
- [Known Bugs & Limitations](#known-bugs--limitations)

---

## Before You Debug

A serial monitor attached to the ESP32 is your best friend. Open it before you power anything up:

```bash
pio device monitor
```

Default baud rate: **115200**. The monitor uses the `esp32_exception_decoder` filter, which decodes Guru Meditation addresses into file names and line numbers automatically.

The boot log tells you nearly everything: firmware version, chip ID, PSRAM size, free heap, Wi-Fi connection result, task start confirmations, and — if anything goes wrong — what failed and why. Read it before trying anything else.

**Key log messages to know:**

| Message | Meaning |
| --- | --- |
| `=== Mikoy Laser FW x.x.x ===` | Firmware started successfully |
| `Config loaded. DMX=x Hostname=x` | NVS config loaded OK |
| `WiFi connected: x.x.x.x (RSSI -xx dBm)` | STA mode connected |
| `AP started: galvOS` | AP mode started (no STA credentials) |
| `Ring buffer overflow #N` | Pattern engine is generating frames faster than the ISR drains them — see [Optimizer Issues](#optimizer--pattern-quality-issues) |
| `TASK FAILED: name (Heap=N)` | A FreeRTOS task could not be created — internal heap exhausted at boot |
| `last_failsafe: reason` | Why the safety system refused to arm last time |
| `[heap] after patterns::init: N B free` | Internal DRAM available after startup; should be ≥30 KB |

---

## Reading the Serial Log

Log levels in GalvOS:

- `I` (INFO) — normal operation, printed in white/default
- `W` (WARN) — something unexpected but recoverable
- `E` (ERROR) — something failed; operation may be degraded

The WebUI Log tab (streaming over WebSocket) shows the same output. It auto-refreshes only when the Log tab is active.

If the ESP32 crashes with a Guru Meditation error, the serial monitor prints a backtrace. With the `esp32_exception_decoder` filter active in PlatformIO, the addresses are decoded into source file names and line numbers. Copy the full crash output — it is the fastest path to finding the bug.

---

## Boot & Connectivity Issues

### No serial output at all

**Cause:** Wrong serial port, wrong baud rate, or USB cable is charge-only (no data lines).  
**Fix:** Verify you are using the UART USB port on the DevKitC-1 (labeled "UART", not "USB"). Try a different cable. Confirm `monitor_speed = 115200` in `platformio.ini`.

### Firmware boots but immediately restarts in a loop

**Cause A:** Heap exhausted during task creation.  
**Diagnosis:** Serial log shows `TASK FAILED: name (Heap=N)` with N near zero.  
**Fix:** Something is allocating on internal DRAM that should be in PSRAM. Check that `BOARD_HAS_PSRAM` is defined and that the N16R8 OPI PSRAM is detected (`PSRAM: 8388608` in boot log).

**Cause B:** Panic handler fired — laser turned off, `esp_restart()` called.  
**Diagnosis:** Serial log shows `Guru Meditation` or `abort()` before the restart.  
**Fix:** Decode the backtrace with `esp32_exception_decoder`. The `last_failsafe` field in `/api/state` stores the reason in RTC memory across restarts.

### No Wi-Fi AP appears after first flash

**Cause:** LittleFS not flashed — WebUI missing, but this should not prevent AP from starting.  
**Fix:** Use `pio run --target upload_all`, not just `upload`. Confirm AP starts in serial log: `AP started: galvOS`.

### WebUI loads but shows "-- none --" everywhere

**Cause:** JavaScript running but API calls failing — server not yet ready, or a route is returning errors.  
**Diagnosis:** Open browser DevTools → Network tab. Look for failed `/api/state` calls.  
**Fix:** Wait 5–10 seconds after boot for all tasks to initialise. If still failing, check serial log for errors.

### mDNS hostname (`galvOS.local`) not resolving

**Cause:** mDNS not supported on some networks (corporate Wi-Fi, VPNs) or Windows without Bonjour.  
**Fix:** Use the IP address directly. Find it in the Dashboard → System card, or in the serial log: `WiFi connected: x.x.x.x`.

### Wi-Fi scan (Configuration tab) returns "error" or hangs

**Cause:** `WiFi.scanNetworks()` on the Arduino core has several failure modes on the ESP32-S3 — a busy-bit that stays stuck after a mode switch, `WIFI_SCAN_FAILED` while STA is mid-(re)connect, or an async completion event that doesn't reliably fire under load. All were seen in the field between v6.00.3 and v6.00.7.  
**Fix:** As of v6.00.7, the scan handler calls `esp_wifi_scan_start()`/`esp_wifi_scan_get_ap_records()` directly instead of going through `WiFiScanClass`, retries up to 3× on any negative result code, and reports a distinct `"error"` status to the UI instead of silently looping. If a scan still fails repeatedly, check the serial log for `esp_err_to_name()` plus internal-heap headroom — `esp_wifi_scan_start()` needs a contiguous internal-DRAM block, so heap pressure (see [Memory & Stability Issues](#memory--stability-issues)) is a plausible root cause of a stubborn failure.  
**Note:** An AP-mode (SoftAP) scan returning 0 networks is a separate, unfixable ESP-IDF channel-lock limitation — enter the SSID manually instead.

### Wi-Fi drops and does not reconnect

**Cause:** The Wi-Fi watchdog task detects the drop and sets `s_wifi_services_started = false`. `setAutoReconnect(true)` handles reconnection automatically.  
**Diagnosis:** Serial log shows `WiFi dropped, will auto-reconnect`, followed by a reconnection or continued attempts.  
**Fix:** Usually self-resolves. If it does not, check signal strength (RSSI). Values worse than −75 dBm cause intermittent drops.

---

## Galvo Issues

### Galvos go crazy when SD card is inserted

**Cause:** SD card wired onto the DAC8562's SPI2 pins; the GPIO matrix let SD's real SPI3 traffic overwrite the DAC's clock/data lines. Fixed in firmware v5.90.0, but requires a physical rewire (SD → GPIO5/6/1/42) — see [Known Issues](09-known-issues-and-todos.md).  
**Fix (until rewired):** Do not insert the SD card.

### Output is mirrored horizontally

**Fix:** Calibration tab → Invert X checkbox → Save calibration.

### Output is mirrored vertically

**Fix:** Calibration tab → Invert Y checkbox → Save calibration.

### Output is rotated 90°

**Cause:** X and Y galvo channels are wired in reverse.  
**Fix:** Calibration tab → Swap X/Y checkbox → Save calibration.

### Image is off-center

**Fix:** Calibration tab → X Offset / Y Offset sliders. Use the Crosshair calibration pattern as a reference. Save calibration.

### Image is too large or too small

**Fix:** Calibration tab → X Gain / Y Gain sliders (use "Linked" to keep aspect ratio). Or adjust the Size slider in Global Controls (Presets tab) per-session.

### Visible ringing / oscillation on blank jumps

**Cause:** The galvo mirror is oscillating at its natural mechanical resonance frequency after arriving at a new position.  
**Fix — Quick:** Increase `blank_samples` in the Optimizer tab. More settle ticks give the mirror more time to damp out.  
**Fix — Proper:** Measure `ring_freq_hz` and `ring_damping_ratio` with an oscilloscope (step response on the galvo feedback signal), then enable `ringing_comp_enabled`. See [Chapter 5 — ZV Ringing Compensation](05-optimizer.md#stage-8--zv-ringing-compensation-pillar-3).

### Corners look rounded or don't meet

**Cause A:** Not enough corner dwell points.  
**Fix:** Increase `max_corner_pts` in the Optimizer tab.

**Cause B:** `galvo_kpps` set too high for the scan angle. The galvo cannot settle at the corner before the next edge starts.  
**Fix:** Reduce `galvo_kpps` (Projection tab). Run the Autotune to find the safe maximum.

### Closed shape has a visible gap instead of reconnecting

**Cause (fixed in v6.05.0):** At a heavily tuned-down `max_pts_per_frame`, corner dwell was treated as fixed overhead — only interior density was ever scaled back to fit the frame budget. On a many-vertex closed shape (Octagon and up, dense Lissajous/rose/trochoid curves, Concentric Rings), corner dwell alone could exceed what was left of the budget, and the point emitter silently stopped mid-shape — always cutting off the final edge and closing dwell first, which reads as "the shape doesn't close."  
**Fix:** The optimizer now scales `min_corner_pts`/`max_corner_pts` down together (floor: 1 point per vertex) whenever corner dwell alone doesn't fit the budget, trading corner sharpness for a guaranteed closed loop. This is automatic — no configuration needed. If you still see a gap on current firmware, `max_pts_per_frame` is too low even for 1 point per vertex; raise it in the Optimizer tab.

### Straight lines look curved

**Cause:** The galvo mirror is still settling from a blank jump when the first interior points of the edge are being drawn.  
**Fix:** Increase `blank_samples` and `min_blank_samples`. Ensure the smoothstep blanking is active (it always is — but increasing the sample count gives it more travel time).

### Image flickers or strobes at high frame rates

**Cause:** Ring buffer overflow — the pattern engine is pushing frames faster than the ISR is draining them. Serial log: `Ring buffer overflow #N`.  
**Fix:** Reduce `opt_max_pts_per_frame` in the Optimizer tab (fewer points per frame = higher frame rate). The Autotune function in the Projection tab finds the highest safe kpps for the current pattern.

### DAC output stuck at 0x8000 (center)

**Cause A:** `gDebugNoHW = true` — No-HW mode is active, DAC writes are skipped.  
**Fix:** Configuration tab → Debug → No-HW Mode → disable → reboot.

**Cause B:** DAC8562 /CLR line held low.  
**Fix:** Verify `PIN_DAC_CLR_N` (GPIO13) pull-up to +5V (R_CLR 10 kΩ). Measure GPIO13 with a multimeter — it should read ~3.3V after boot.

---

## Laser Issues

### Laser fires at boot before ARM

**What is happening:** The fail-safe pull-ups (R_FSR/G/B, 10 kΩ → +3.3V) on GPIO7/8/21 hold the GPIOs HIGH during boot. This makes the 6N137 LEDs dark, which pulls the optocoupler outputs to +1.65V (HIGH) — which is "laser ON" for the MN-1M5AT active-HIGH driver.  
**Why this is expected:** This is the correct fail-safe behaviour for the TTL signals. However, the laser power rail is controlled by PIN_LASER_ENABLE (GPIO38 → SSR1), which the safety system holds LOW until all conditions are satisfied. The laser cannot actually fire until `safety::allOk()` returns true and the user presses ARM.  
**If the laser fires anyway:** The SSR1 is being energised before ARM. Check R_PD_EN (10 kΩ pull-down on GPIO38 → GND) is fitted. Measure GPIO38 at boot — it must be LOW before ARM.

### Laser does not turn on after ARM

**Cause A:** `master_dimmer = 0`.  
**Diagnosis:** Dashboard → Telemetry → Master Dimmer shows 0.  
**Fix:** Set Master Dimmer > 0 via the WebUI DMX override or DMX CH1. The guard `max(master_dimmer, ui_master_dimmer)` means both must be zero to produce no output.

**Cause B:** SSR1 not wired correctly, or relay contact open.  
**Diagnosis:** GPIO38 goes HIGH on ARM (measure with multimeter). If GPIO38 is HIGH but the laser power rail is still dead, the SSR or relay is the fault.  
**Fix:** Verify SSR1 wiring (IN+ from R_EN 1 kΩ to GPIO38, IN− to GND). Check SSR1 output contacts are in the laser power rail.

**Cause C:** `safety_override = false` and a safety condition is not met.  
**Diagnosis:** Dashboard → Safety Status shows a red LED. The `fault_reason` field shows which condition failed.  
**Fix:** Resolve the indicated condition (E-Stop wiring, scan-fail NE555 timing, watchdog heartbeat).

### One color channel missing

**Cause A:** 6N137 for that channel not powered or failed.  
**Diagnosis:** Measure +5V at that 6N137's VCC pin (Pin8) and VE pin (Pin7).  
**Fix:** Check power wiring to U_6N_R/G/B Pin8 and Pin7 → +5V_BUCK.

**Cause B:** Open circuit in the series resistor (R_R/G/B 220 Ω) or the GPIO → resistor trace.  
**Diagnosis:** Measure voltage across the 220 Ω resistor while that channel should be active.  
**Fix:** Re-solder or replace R_R/G/B.

**Cause C:** Firmware LEDC channel detached.  
**Diagnosis:** Check serial log for LEDC errors at boot.  
**Note:** `ledcAttachPin()` is called once at `setup()` — never per blank/unblank cycle. If you see this error, something is calling it in a loop.

### Colors washed out or wrong after a color animation

**Cause:** The color animation left `col_override = true` with an unintended color. The `_stopGradient()` function must send `col_override: false` to clear it.  
**Fix:** Presets tab → Global Controls → **↺ Reset Colors** button. This calls `resetColorOverride()` which explicitly sends `col_override: false` to the firmware.

### Master Dimmer set to 100% but laser is very dim

**Cause:** `thresh_r/g/b` thresholds are set too high — the `mapVisibleRange()` function is compressing the effective range.  
**Fix:** Run the visibility threshold calibration (Calibration tab → Start test beam → adjust Base R/G/B sliders). Alternatively, reduce the threshold values manually if you know your diodes' actual dead zone.

---

## Color & Calibration Issues

### Base color sliders in Calibration have no effect

**Cause:** The test beam bypass is not active. `mapVisibleRange(255, any_threshold)` always returns 255 — a full-brightness signal bypasses the threshold mapping.  
**Fix:** Press **▶ Start test beam** in the Calibration tab before adjusting threshold sliders. The test beam sends a logical level of ~1 (not 255), which goes through `mapVisibleRange()` and is therefore controlled by the threshold value.

### Colors look blown out at mid-brightness (gamma issue)

**Cause A:** Gamma enabled on a laser driver that already applies its own gamma correction — double-gamma.  
**Fix:** Calibration tab → CIE 1931 Gamma → toggle off. Save calibration.

**Cause B:** `calib_patterns.cpp:colorOut()` applies `applyGamma()` before storing into `LaserPoint.r/g/b`, but `galvo_out.cpp:rgbWrite()` applies it again.  
**Diagnosis:** This is a firmware bug pattern to be aware of when modifying calibration patterns. Each color value should go through gamma exactly once.

### Three-Circle Pattern colors do not match visually

**Cause:** White balance gains (gain_r/g/b) not calibrated for your laser module's actual power.  
**Fix A — Manual:** Calibration tab → Start Three Circle Pattern → adjust Gain R/G/B until all circles look equally bright.  
**Fix B — Auto:** Press **🪄 Auto White Balance** — computes gains from the power values in the Projection tab using V(λ) weighting. Only accurate if the power values (`power_r_mw`, `power_g_mw`, `power_b_mw`) are correct for your module.

### Calibration pattern looks wrong or produces incorrect output

**Cause:** Known issue with some calibration patterns. See [Known Issues](09-known-issues-and-todos.md).

---

## Optimizer & Pattern Quality Issues

### Pattern flickers

**Cause A:** Frame rate too low — `opt_max_pts_per_frame` too high.  
**Diagnosis:** Dashboard → Telemetry → Galvo Rate shows pps lower than expected. Serial log shows `Ring buffer overflow`.  
**Fix:** Reduce `opt_max_pts_per_frame` in the Optimizer tab until the overflow stops.

**Cause B:** Ring buffer underrun — pattern engine is generating frames too slowly (complex patterns at low kpps).  
**Diagnosis:** Serial log shows underrun messages.  
**Fix:** Reduce pattern complexity or increase `galvo_kpps`.

### No improvement in image quality above 1300 points per frame

**This is expected.** The known effective limit on the JY-15K-BL at 30 kpps is 1300 points per frame. Above this, the per-point time budget (33 µs) is the limiting factor, not the number of points. Setting `opt_max_pts_per_frame` above 1300 wastes frame budget without improving optical quality.

### Wireframe corners look bad (rounded or missing)

**Cause:** `buildWfChains()` not called for this wireframe pattern. Isolated 2-vertex `PathSegment` entries prevent `has_incoming && has_outgoing` from ever being true, so corner dwell never fires.  
**Fix:** This is a firmware-side issue. When writing new 3D patterns, ensure `buildWfChains()` is called to group edge pairs into proper chains before passing to the optimizer.

### Optimizer parameter changes have no effect

**Cause:** The pattern cache is serving a stale cached result. `gPatternCacheGen` was not incremented after the optimizer parameter change.  
**Diagnosis:** Change a non-optimizer parameter (e.g. speed), then change back — this forces a cache invalidation.  
**Expected behaviour:** Any optimizer parameter change via the WebUI automatically bumps `gPatternCacheGen`. If you are changing parameters directly in NVS without going through the WebUI, you may need to restart.

### PPS scaling produces unexpected densities

**Cause:** `galvo_rated_kpps` not set correctly for your galvo.  
**Fix:** Projection tab → set Galvo Rated Speed to your galvo's datasheet kpps. The optimizer uses the ratio `rated_kpps / galvo_kpps` to scale density. If rated_kpps is wrong, all scaled values will be wrong.

---

## WebUI Issues

### WebUI does not load (connection refused or timeout)

**Cause A:** LittleFS not flashed — `data/index.html` missing.  
**Fix:** Run `pio run --target upload_all`.

**Cause B:** ESP32 in AP mode and you are not connected to the `galvOS` AP.  
**Fix:** Connect your device to the `galvOS` Wi-Fi network, then open `http://192.168.4.1`.

**Cause C:** mDNS not resolving `galvOS.local`.  
**Fix:** Use IP address directly (see Dashboard → System, or serial log).

### Preset grid is empty

**Cause:** `/api/presets` request failed — server busy or route error.  
**Fix:** Reload the tab. If persistently empty, check the serial log for errors on the `/api/presets` handler. The WebUI falls back to the static `STATIC_PRESET_DEFS` SVG lookup for thumbnails, but the grid itself requires the API.

### API returns 404 for `/api/calib-pattern/stop` or `/api/text/vertices`

**Cause:** Route registration order issue in ESPAsyncWebServer. These specific routes must be registered before any prefix-matching wildcard routes (`/api/calib-pattern/*`). This is a known architectural constraint — if you add new routes, keep this rule in mind.  
**Fix:** In `web_ui.cpp`, verify `/api/calib-pattern/stop` is registered before any prefix handler that would match `/api/calib-pattern/...`.

### Controls in the WebUI lag or don't respond

**Cause A:** Core 0 CPU load too high — WebSocket messages are being dropped.  
**Diagnosis:** Dashboard → CPU Load graph shows Core 0 near or above 90%.  
**Fix:** Reduce pattern complexity or close extra browser tabs connected to the device.

**Cause B:** Wi-Fi interference or weak signal causing packet loss.  
**Diagnosis:** Dashboard → System → WiFi Signal weaker than −70 dBm.  
**Fix:** Move ESP32 or access point closer together, or switch Wi-Fi channels.

---

## ILDA & SD Card Issues

### SD card causes galvo malfunction

**Cause:** SD card wired onto the DAC8562's SPI2 pins; the GPIO matrix let SD's real SPI3 traffic overwrite the DAC's clock/data lines. Fixed in firmware v5.90.0, but requires a physical rewire (SD → GPIO5/6/1/42) — see [Known Issues](09-known-issues-and-todos.md).  
**Fix (until rewired):** Remove the SD card. All other features work normally without it.

### ILDA files not listed in the ILDA tab

**Cause A:** SD card not formatted as FAT32.  
**Fix:** Format the card as FAT32 (not exFAT, not NTFS). Maximum 40 `.ild` files indexed.

**Cause B:** SD card speed class insufficient.  
**Fix:** Use Class 10 UHS-I minimum. Class 4 cards are incompatible with reliable SPI access at DAC-sharing speeds.

---

## Safety System Issues

### System refuses to ARM — no obvious reason

**Diagnosis:** Dashboard → Safety Status card → `fault_reason` text line. Also check `last_failsafe` in `/api/state` JSON, which survives restarts and shows the last hardware-level shutdown reason.

**Common conditions and fixes:**

| Fault reason | Cause | Fix |
| --- | --- | --- | --- |
| `estop` | E-Stop circuit open | Check J_ESTOP wiring. Pin1 must be pulled to +3.3V via R_ESTOP (10 kΩ). Shorting Pin2 to Pin1 disables E-Stop. |
| `scanfail` | NE555 scan-fail timer timed out | DAC must be producing output on VOUTA for the scan-fail NE555 (U11) to be triggered. Starts a preset before arming. Also check C_T/R_T values on U11. |
| `watchdog` | NE555 hardware watchdog timeout | GPIO14 heartbeat pulse from firmware not arriving at U12 TRIG. Check R_HB (1 kΩ) and NE555 U12 wiring. |
| `thermal` | Temperature above shutdown threshold | Check temperature sensors in Thermal tab. Default shutdown at 70°C. |
| `user` | User has not pressed ARM | Press the ARM button on the Dashboard. |

### Laser cuts out mid-operation

**Cause A:** Hardware watchdog timeout — firmware loop exceeded `watchdog_period_ms`.  
**Diagnosis:** Serial log shows watchdog-related messages. `last_failsafe` in RTC memory.  
**Fix:** Usually caused by a hang on Core 0 (Wi-Fi, heavy JSON serialisation). Reduce WebUI polling frequency if you have custom integrations. Check for memory allocation failures.

**Cause B:** Temperature exceeded `temp_shutdown_c` (default 70°C).  
**Diagnosis:** Dashboard → Temperature History chart.  
**Fix:** Check fan operation. Verify thermal paste on laser diode module. Reduce `temp_shutdown_c` threshold if your setup runs hotter than expected for a softer warning margin.

**Cause C:** E-Stop button physically pressed or J_ESTOP connector loose.  
**Fix:** Verify E-Stop connector is seated. Check R_ESTOP (10 kΩ) pull-up is present.

### Scan-fail fires spuriously

**Cause:** NE555 U11 timing too aggressive for the configured kpps. At very low kpps, DAC updates are infrequent and the AC coupling (C_AC 100 nF) may not trigger the NE555 TRIG pin reliably.  
**Fix:** Increase `scanfail_timeout_ms` in the Configuration tab. Or increase `galvo_kpps` so DAC output is more frequent.

---

## Memory & Stability Issues

### Crash on boot — `Guru Meditation Error: Core 0 panic'ed`

**Most common cause:** Internal DRAM heap exhaustion during task creation or large allocation.

**Diagnosis:** Boot log line `[heap] after patterns::init: N B free`. Should be ≥ 30,000 bytes. If N < 10,000, something is allocating on DRAM that should be in PSRAM.

**Allocation rules:**

- Buffers > 16 KB → `ps_malloc()` or `heap_caps_malloc(MALLOC_CAP_SPIRAM)`
- All `JsonDocument` instances → `JsonDocument doc(&jsonAllocator())` (uses `SpiRamAllocator`)
- API responses → `sendJsonPsram()` (chunked, PSRAM buffer)

**Fix:** If you have added code that allocates large buffers, move them to PSRAM.

### `heap_critical_bytes` threshold triggered restart

**What happens:** If the largest free block of internal DRAM falls below `heap_critical_bytes` (default 6144 bytes), the firmware calls `esp_restart()`. This prevents the system from reaching a state where even small allocations fail and cause undefined behaviour.

**Diagnosis:** Serial log shows a restart with no Guru Meditation. Check `last_failsafe`.

**Fix A:** If this is triggered by normal operation, the `heap_critical_bytes` threshold may be set too conservatively for your configuration. Increase it slightly with caution.  
**Fix B:** If this is triggered by a specific action (opening a tab, loading a preset), that action is causing an unexpected internal DRAM allocation. Profile with the Log tab open.

### PSRAM not detected

**Symptom:** `PSRAM: 0` in the boot log. All PSRAM allocations fail silently.  
**Cause A:** Wrong board variant — must be N16R8, not N8R8 or no-PSRAM variant.  
**Cause B:** `board_build.psram_type = octal` or `board_build.arduino.memory_type = qio_opi` missing from `platformio.ini`.  
**Fix:** Verify `platformio.ini` settings. Verify the physical chip marking on the ESP32 module reads `N16R8`.

---

## Known Bugs & Limitations

A quick-reference index of open issues documented in [Chapter 9](09-known-issues-and-todos.md):

| Issue | Impact | Workaround |
| --- | --- | --- |
| SD card causes galvo malfunction | ILDA playback non-functional | Remove SD card |
| Text: Bounce has no effect | Minor | Use Scroll or Static |
| Text: Typewriter runs once only | Minor | — |
| Text: Star Wars Scroll direction wrong | Minor | Use Scroll Left/Right |
| Text: Star Wars renders as dots | Minor | — |
| Calibration channel selector not working | Minor | Calibrate with RGB combined |
| ILDA Standard Test Pattern bad output | Minor | Use Crosshair/Grid patterns instead |

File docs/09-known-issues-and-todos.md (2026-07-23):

# Chapter 9 — Known Issues & Todos

> This is an honest list. Every project has rough edges — GalvOS more than most, because it is a one-person hardware/firmware/UI project that started as a dimmer fix and grew considerably beyond that. Nothing here is hidden. If you run into one of these, you are not doing it wrong.

## Table of Contents

- [Critical Issues](#critical-issues)
- [Hardware Issues](#hardware-issues)
- [Pattern Issues](#pattern-issues)
- [Text Mode Issues](#text-mode-issues)
- [Calibration Issues](#calibration-issues)
- [UI Issues](#ui-issues)
- [Planned Features](#planned-features)
- [Contributing a Fix](#contributing-a-fix)

---

## Critical Issues

These affect core functionality and should be resolved before relying on those features in production.

### SD Card Causes Galvo Malfunction

**Severity:** Critical  
**Status:** Fixed in firmware v5.90.0 — **hardware rewire still pending**  
**Symptom:** If an SD card is inserted, the galvos behave erratically — incorrect output, uncontrolled movement.  
**Root cause:** Found. Not bus contention — the SD card was wired onto the DAC8562's SPI2 pins (SCK=GPIO12, MOSI=GPIO11, MISO=GPIO2, CS=GPIO9) under the assumption that Arduino's `SPIClass(HSPI)` attaches to SPI2_HOST on ESP32-S3. It does not: `HSPI` is bound to the independent SPI3 peripheral. Routing SPI3 onto SPI2's GPIOs meant two different peripherals both drove the same pins through the GPIO matrix, which only lets one peripheral own a pin's output at a time — `SPIClass::begin()` silently stole GPIO12/GPIO11 away from the DAC every time SD init ran, and real SD card traffic then appeared on the DAC's own clock/data lines, corrupting its output.  
**Fix:** SD moved to fully independent GPIOs (SCK=GPIO5, MOSI=GPIO6, MISO=GPIO1, CS=GPIO42) on SPI3, with zero pin overlap with the DAC's SPI2 — see `include/pinmap.h` and `hardware/netlist.txt`. **The perfboard has not been rewired yet** — until the 4 SD wires are physically moved to GPIO5/6/1/42, `sd_card::init()` will simply fail to find a card (safe, but SD stays non-functional).  
**Impact:** ILDA file playback from SD card is non-functional until the rewire is done. ILDA files loaded via other means (Art-Net, Ether Dream) are unaffected.  
**Workaround (until rewired):** Leave the SD card slot empty. All other features (presets, WebUI, DMX, Art-Net) work normally.

---

## Hardware Issues

### OPA4134 Gain Deviation

**Status:** Known, compensated in firmware  
**Detail:** The OPA4134 feedback resistors R2/R4 are 22 kΩ instead of the theoretical 10 kΩ, resulting in a gain of 2.2× rather than 2.0×. This means the full DAC swing would produce slightly more than ±5V at the galvo input. Compensated via `dac_limit_min`/`dac_limit_max` in `RuntimeConfig` (default: 0x0666..0xF999, ≈95% of full range). No action required unless you replace the resistors.

---

## Pattern Issues

None atm :-)

---

## Text Mode Issues

### Bounce Animation — No Effect

**Status:** Open  
**Symptom:** Selecting the "Bounce" animation in Text mode has no visible effect. The text renders statically.

### Typewriter Animation — Runs Once Only

**Status:** Open  
**Symptom:** The Typewriter animation plays through once and stops. It does not loop.

### Orbit Animation — Rotation Direction

**Status:** Open  
**Detail:** The Orbit animation's rotation direction is fixed and cannot be switched. A control to reverse the direction is planned.

### Star Wars Scroll — Two Issues

**Status:** Open  
**Symptom 1:** The scroll direction is incorrect (text moves in the wrong direction).  
**Symptom 2:** The text renders as dots only instead of the expected vector strokes.

---

## Calibration Issues

### Several Calibration Patterns Need Fixing

**Status:** Open  
**Detail:** A subset of calibration patterns produce incorrect or unexpected output. Specific patterns affected are under investigation.

### Channel Parameter Not Working

**Status:** Open  
**Detail:** The per-channel selector in the calibration flow does not correctly isolate individual channels in all cases.

### ILDA Standard Test Pattern — Incorrect Output

**Status:** Open  
**Symptom:** The ILDA standard test pattern (used to verify galvo linearity and speed) does not render correctly. This makes it unsuitable as a calibration reference until resolved.
**Solution:** Remove completely as not needed

---

## UI Issues

### Features Not Toggleable via UI

**Status:** Planned  
**Detail:** Some subsystems (e.g. Art-Net receiver) are always active after boot, regardless of whether they are in use. The ability to enable/disable individual features from the WebUI is planned. This would reduce background CPU load and Wi-Fi channel congestion in setups that only use DMX.

---

## Planned Features

These are features that are designed and intended, but not yet implemented.

### ~~Auto-Tuning via Global Shutter Camera~~ — Implemented in v6.03.0–v6.05.0

~~The plan is to add an auto-tuning mode that uses a global-shutter camera input to capture the projected image and automatically calibrate galvo linearity, offset, gain, and potentially optimizer parameters. This would replace the current manual calibration workflow.~~

Done. Firmware v6.03.0 added the `/api/calib-cam/*` camera-in-the-loop calibration API, and the companion `scripts/optimizeGalvo/optimizeGalvo.py` tool (added alongside, now at v2.5.0) drives it end-to-end: pixel↔DAC homography from a 4-dot reference pattern, Optuna-based auto-tuning of the Vector/Smooth/Waves/MultiObject optimizer profiles against camera-measured beam quality, a `diagnose` mode that separates geometry drift from optimizer-setting problems, and an `autotune-camera` mode that tunes the camera's own exposure/gain/threshold instead of firmware parameters. v6.04.1 added per-channel pattern color (patterns default to blue now, to avoid RGB boresight smear on a mono camera) and v6.05.0 fixed a frame-budget edge case where heavily-tuned-down profiles could leave closed shapes not reconnecting.

This does **not** replace the manual galvo geometry calibration (offset/gain/swap/invert) in the Calibration tab — it only auto-tunes optimizer scan/dwell parameters. See the new [Chapter 11 — Camera-in-the-Loop Auto-Tuning](11-camera-autotuning.md) for the full workflow.

**Optimize Heap Usage even more:** ~~117KBs to 121 KBs Untracked Heap Memory usage~~
Fixed in v6.04.0: ~120 KB of `static` scratch buffers (preset/paint/calib pattern
verts, EtherDream RX, SD file table, gPaint canvas, optimizer transform scratch)
moved from DRAM .bss to lazily allocated PSRAM (`src/util/ps_scratch.h`).
Static RAM 180,728 B -> 57,872 B; the "untracked" remainder is the WiFi/lwIP/
AsyncTCP stack plus FreeRTOS task stacks, which cannot leave internal RAM.

---

## Contributing a Fix

If you fix one of the issues above, please see [Chapter 8 — Contributing](08-contributing.md) for the patch workflow and commit message format.

When submitting a fix for a known issue, reference the issue name from this chapter in your commit message body:

```text
Fix Typewriter animation looping

Typewriter now restarts after completing one pass.
Resolves: "Typewriter Animation — Runs Once Only" (docs/09-known-issues-and-todos.md)
```

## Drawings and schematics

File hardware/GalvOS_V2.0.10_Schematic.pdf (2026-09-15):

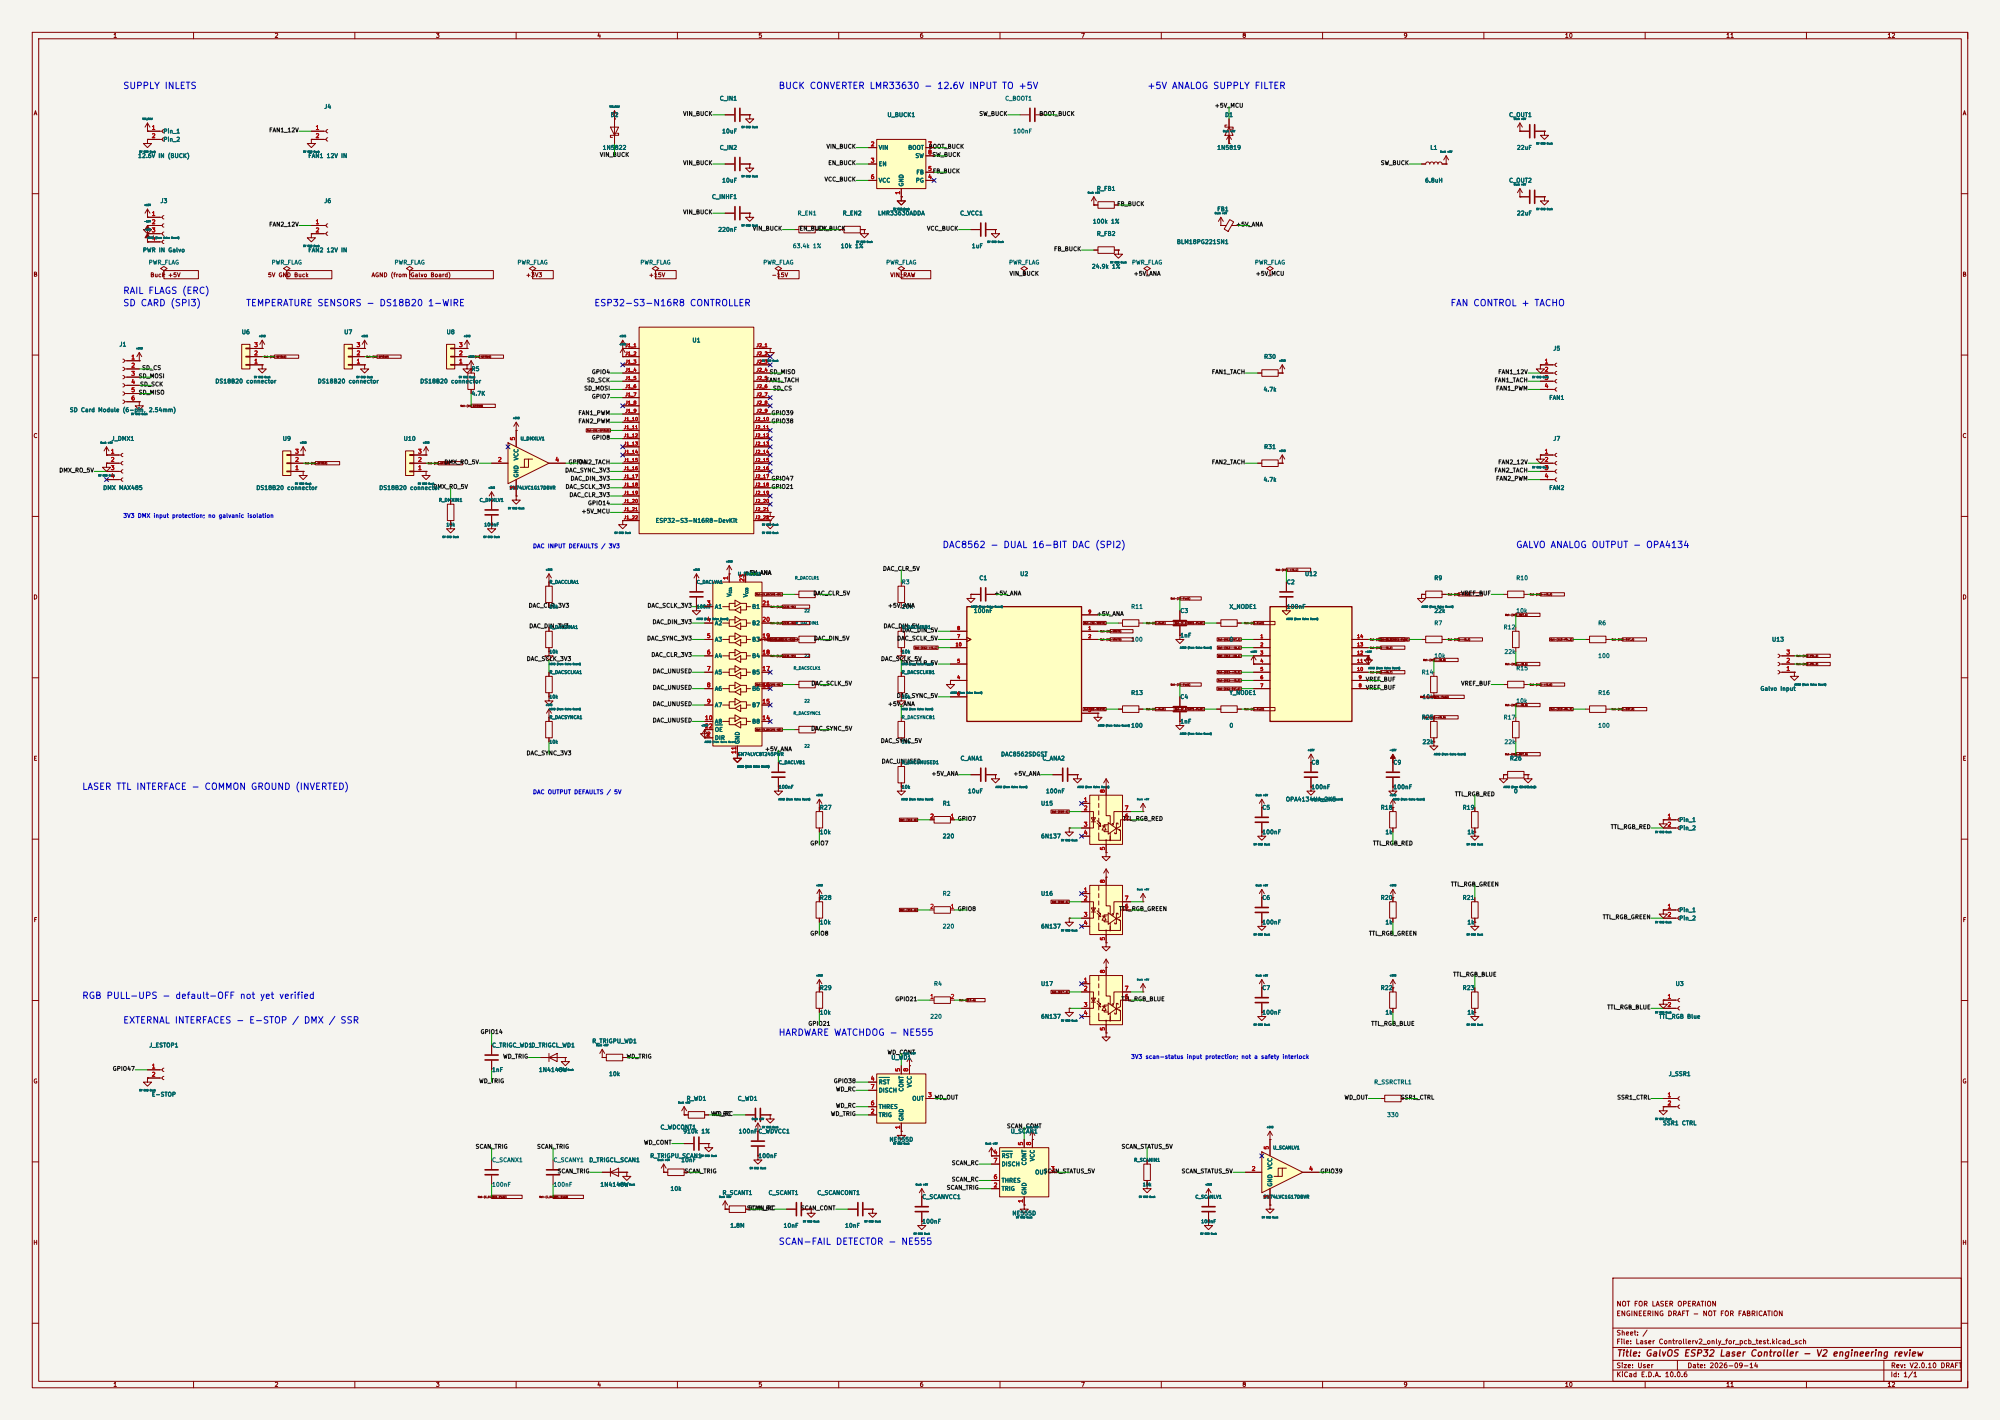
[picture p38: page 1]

5V GND Buck 5V GND Buck C_OUT2

5V GND Buck 5V GND Buck C_INHF1

5V GND Buck

5V GND Buck 5V GND Buck GND

AGND (from Galvo Board) -15V +15V

3V3 DMX input protection; no galvanic isolation RAIL FLAGS (ERC)
DAC_SYNC_3V3 SD CARD (SPI3)

SD Card Module (6-pin, 2.54mm) 1

SD Card Module (6-pin, 2.54mm)

AGND (from Galvo Board) R31

AGND (from Galvo Board) U_DACLV1

ESP32-S3-N16R8-DevKit
AGND (from Galvo Board) C_DACLVA1

AGND (from Galvo Board) C3

AGND (from Galvo Board) C1

+5V_ANA DAC_DIN_5V
AGND (from Galvo Board) AGND (from Galvo Board) R_DACDINB1

AGND (from Galvo Board)

Buck +5V Buck +5V Buck +5V 1

AGND (from Galvo Board) AGND (from Galvo Board) R_DACSYNCA1

AGND (from Galvo Board) AGND (from Galvo Board) R_DACSCLKA1

AGND (from Galvo Board) R_DACSCLKB1
R_DACSCLKB1

AGND (from Galvo Board) AGND (from Galvo Board) +3V3R_DACSYNCA1

AGND (from Galvo Board) 100

AGND (from Galvo Board) R_DACUNUSED1

AGND (from Galvo Board) C9

5V GND Buck AGND (from Galvo Board) R19

AGND (from Galvo 5V GND Board) Buck R26

LASER TTL INTERFACE - COMMON GROUND (INVERTED)

AGND (from Galvo Board) U15

Buck +5V Buck +5V Buck +5V C7
AGND (from Galvo Board) C5

AGND (from Galvo Board) +3V3 R18

5V GND Buck 5V GND Buck 5V GND Buck R21

RGB PULL-UPS - default-OFF not yet verified

EXTERNAL INTERFACES - E-STOP / DMX / SSR

5V GND Buck 5V GND Buck U_WD1 NE555DGND

5V GND Buck 5V GND Buck Buck +5V C_WD1

Buck +5V 5V GND Buck 5V GND Buck C_WDVCC1

NOT FOR LASER OPERATION
ENGINEERING DRAFT - NOT FOR FABRICATION

Sheet: /
File: Laser Controllerv2_only_for_pcb_test.kicad_sch
Title: GalvOS ESP32 Laser Controller - V2 engineering review

Size: User | Rev: V2.0.10 DRAFT
KiCad E.D.A. 10.0.6 | Id: 1/1

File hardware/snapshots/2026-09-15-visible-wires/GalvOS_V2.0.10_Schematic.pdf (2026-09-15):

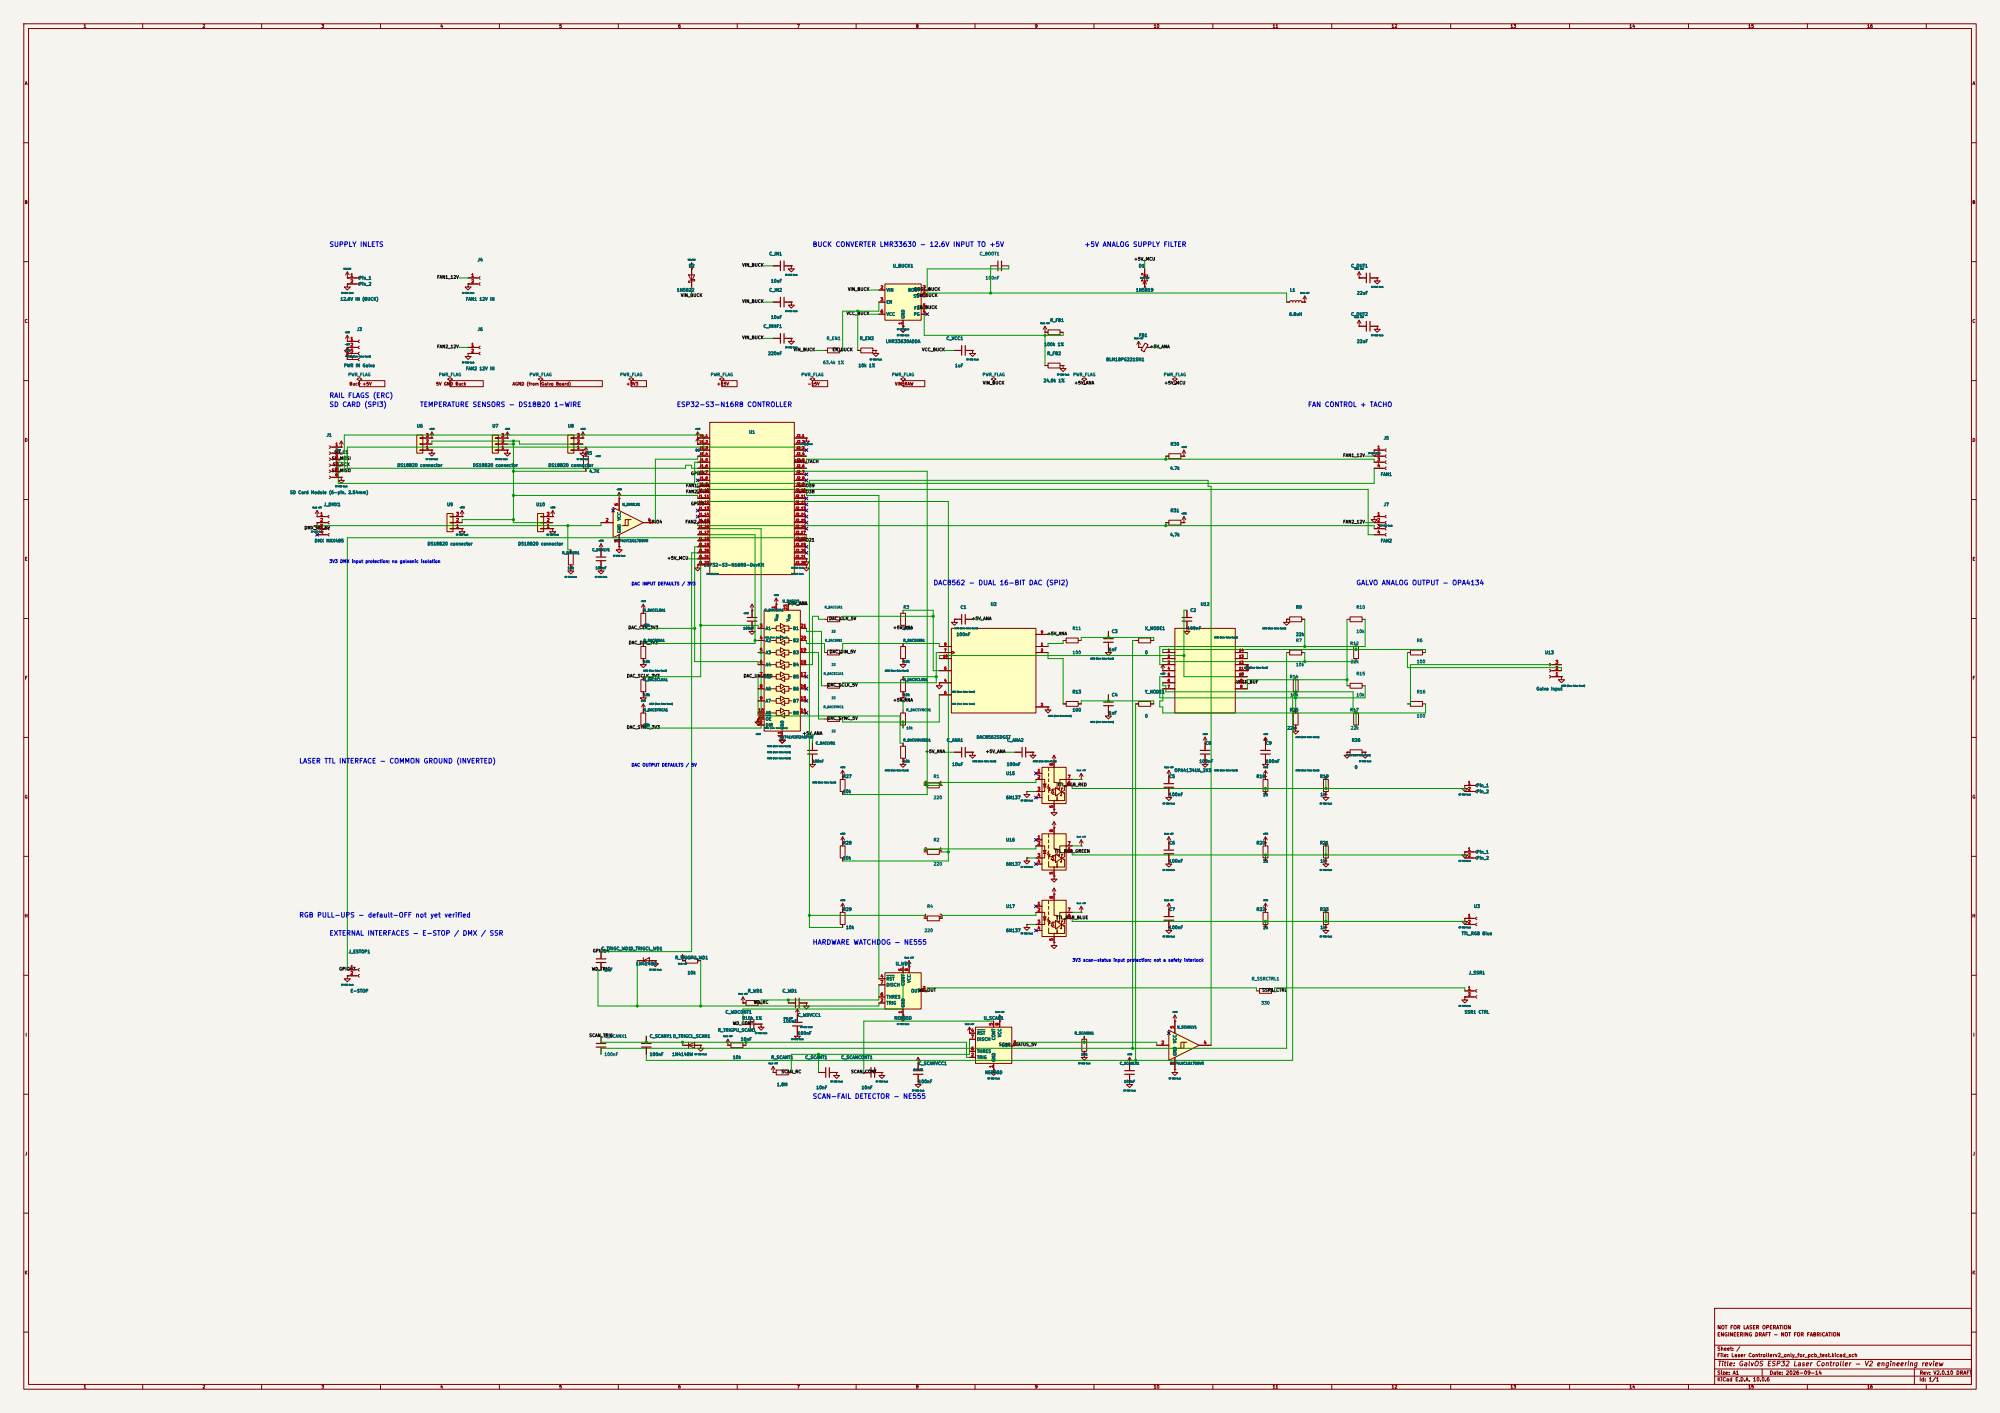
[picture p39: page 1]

5V GND Buck 5V GND Buck C_IN1

5V GND Buck 5V GND Buck D2

5V GND Buck 12.6V IN (BUCK) Pin_1 1 Pin_2 2

5V GND Buck 5V GND Buck 5V GND Buck R_EN2
FAN2 R_EN2

DAC INPUT DEFAULTS / 3V3 TEMPERATURE SENSORS - DS18B20 1-WIRE

5V GND Buck 5V GND Buck J1

3 | 3 | 3 | J1_1
2 2 | | J1_2

SD Card Module (6-pin, 2.54mm) 1

SD Card Module (6-pin, 2.54mm)

AGND (from Galvo Board) R9

+5V_MCU
AGND (from Galvo Board) R_DACCLRA1

J1_21
J1_22

5V GND Buck AGND (from Galvo Board) +3V3R_DACDINA1

AGND (from Galvo Board) R11

AGND (from Galvo Board) AGND (from Galvo Board) U12 OPA4134UA_2K5

AGND (from Galvo Board) C2

AGND (from Galvo Board) C3

AGND (from Galvo Board) -15V

AGND (from Galvo Board) R_DACDINA1

AGND (from Galvo Board)

AGND (from Galvo Board) R_DACSYNC1

AGND (from Galvo Board) R_DACSCLKB1

AGND (from Galvo Board) +3V3R_DACSCLKA1

AGND (from Galvo Board) 1

AGND (from Galvo Board) R13

AGND (from Galvo Board) C4

AGND (from Galvo Board) R_DACSYNCB1

AGND (from Galvo Board) R25

+3V3 C_DACLVB1

AGND (from Galvo Board) R_DACUNUSED1

AGND (from Galvo Board) C_ANA1

AGND (from Galvo Board) R26

LASER TTL INTERFACE - COMMON GROUND (INVERTED)

AGND (from Galvo Board) R27

AGND (from Galvo Board)R19

5V GND Buck 5V GND Buck C6

RGB PULL-UPS - default-OFF not yet verified

EXTERNAL INTERFACES - E-STOP / DMX / SSR

3V3 scan-status input protection; not a safety interlock

5V GND Buck 5V GND Buck U_SCAN1 NE555DGND

5V GND Buck 5V GND Buck +3V3 C_SCANT1

NOT FOR LASER OPERATION
ENGINEERING DRAFT - NOT FOR FABRICATION

Sheet: /
File: Laser Controllerv2_only_for_pcb_test.kicad_sch
Title: GalvOS ESP32 Laser Controller - V2 engineering review

Size: A1 | Rev: V2.0.10 DRAFT
KiCad E.D.A. 10.0.6 | Id: 1/1

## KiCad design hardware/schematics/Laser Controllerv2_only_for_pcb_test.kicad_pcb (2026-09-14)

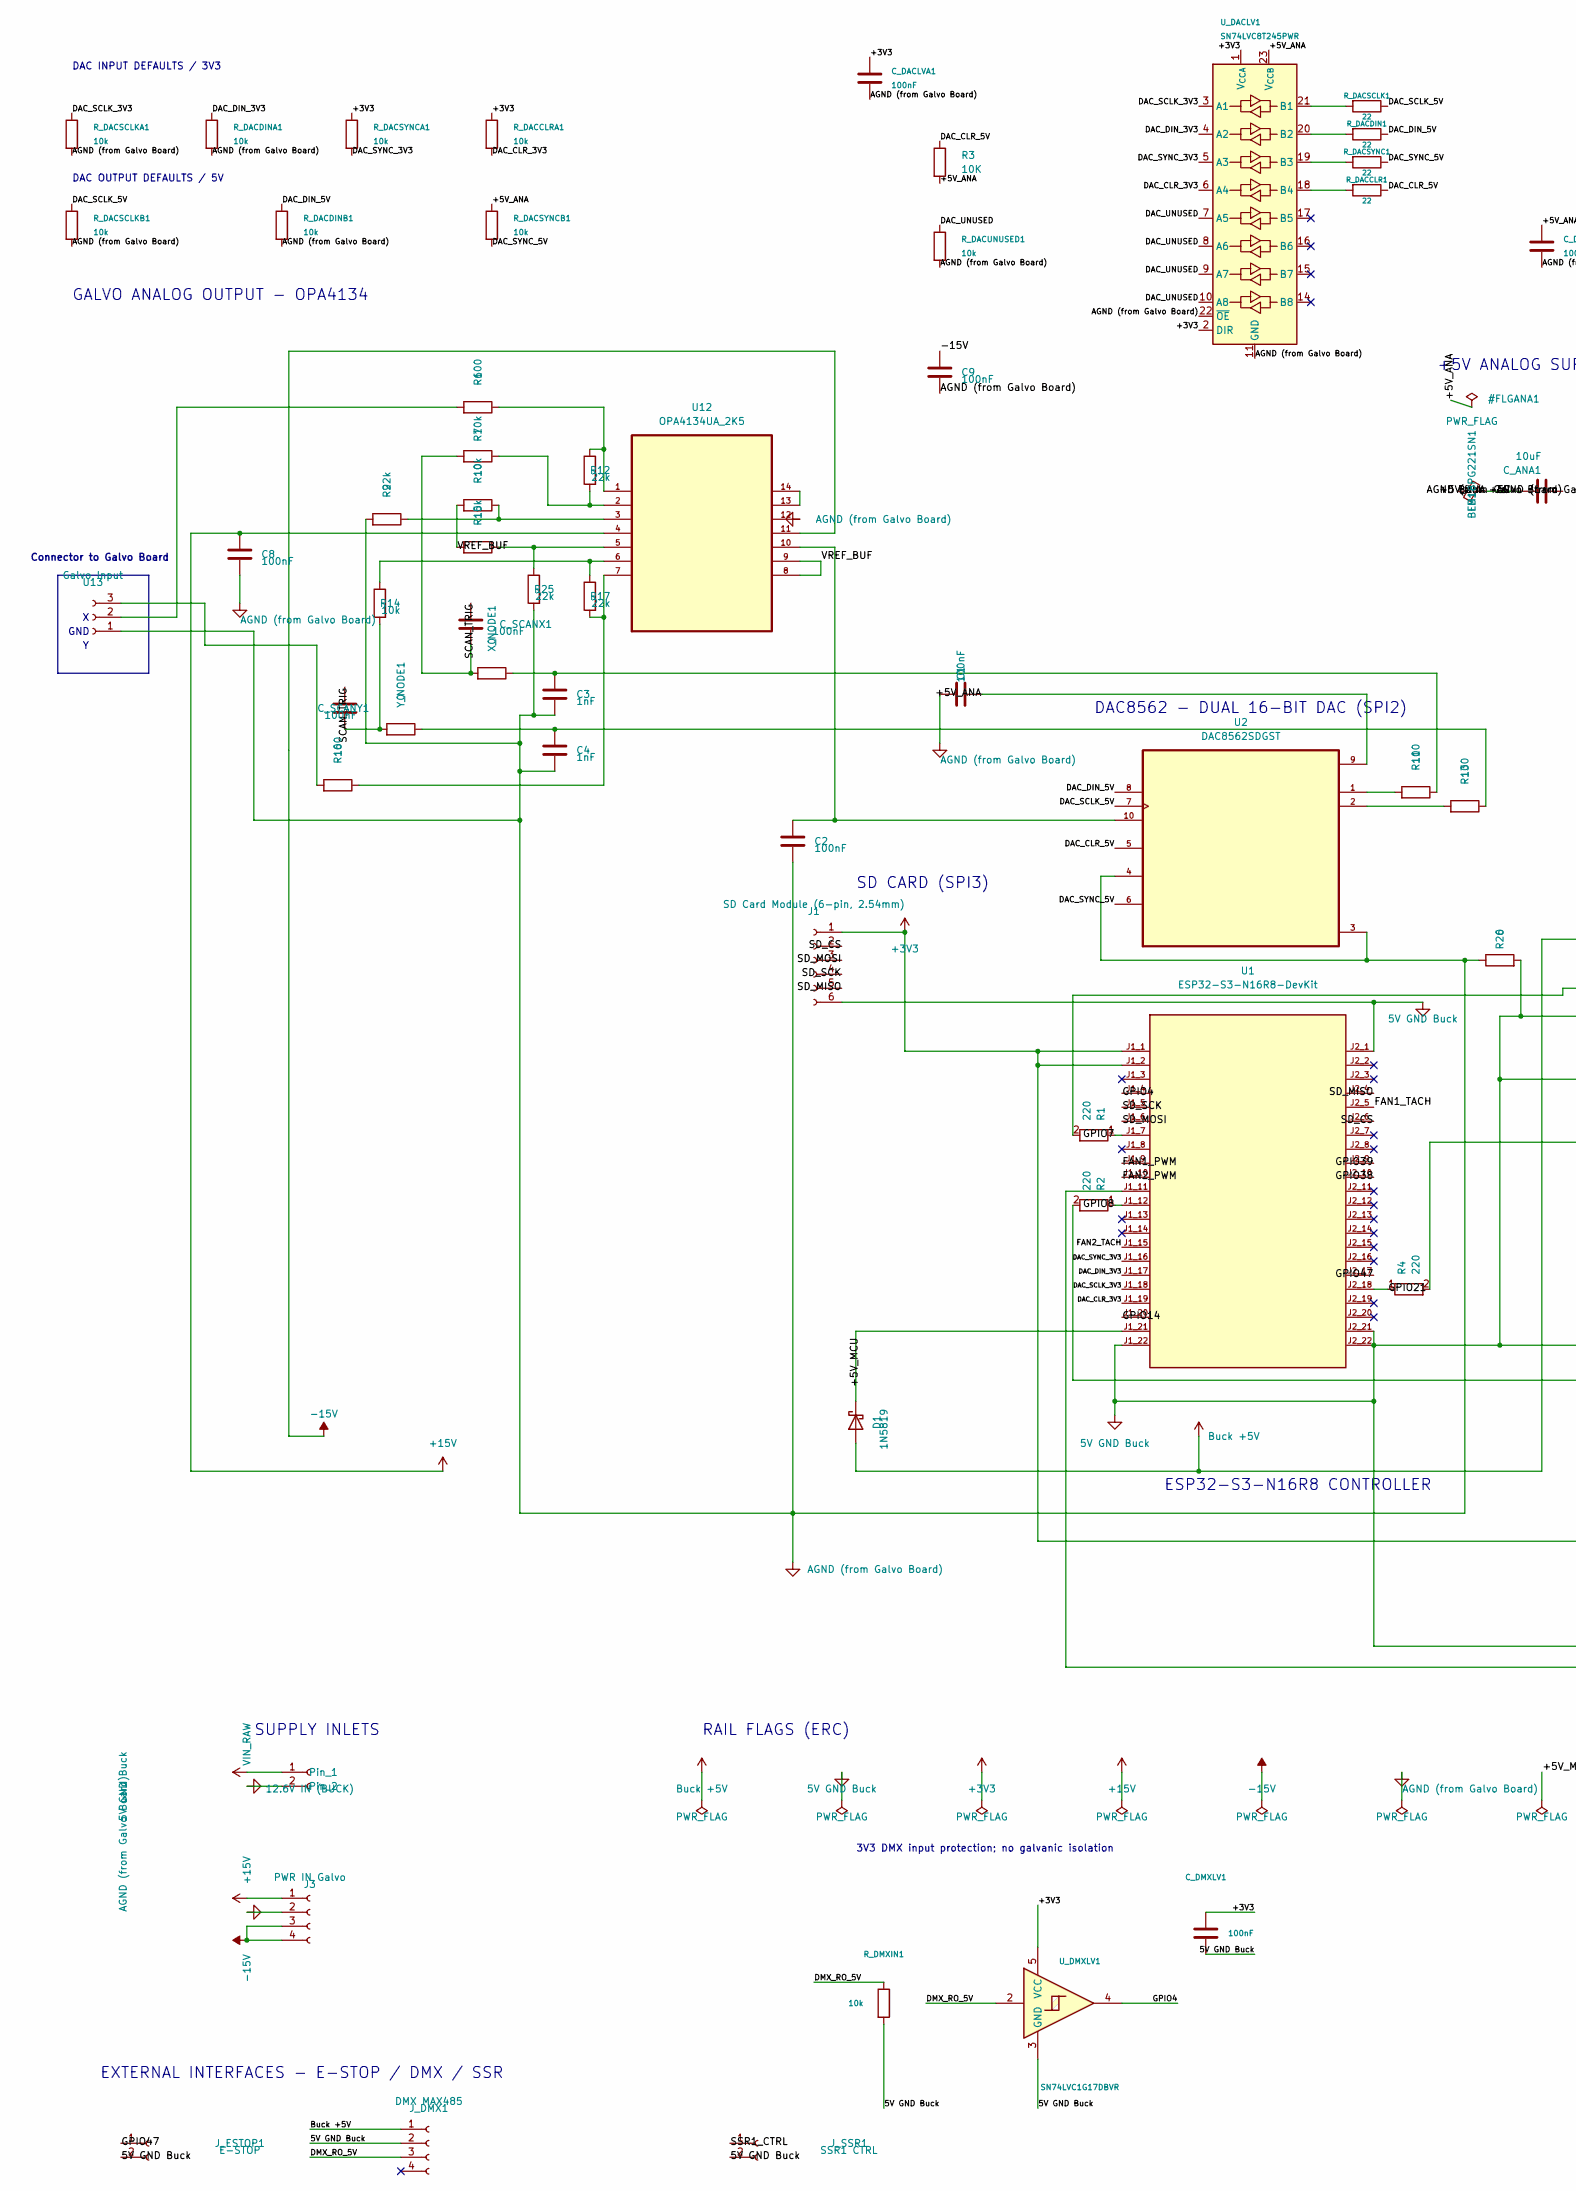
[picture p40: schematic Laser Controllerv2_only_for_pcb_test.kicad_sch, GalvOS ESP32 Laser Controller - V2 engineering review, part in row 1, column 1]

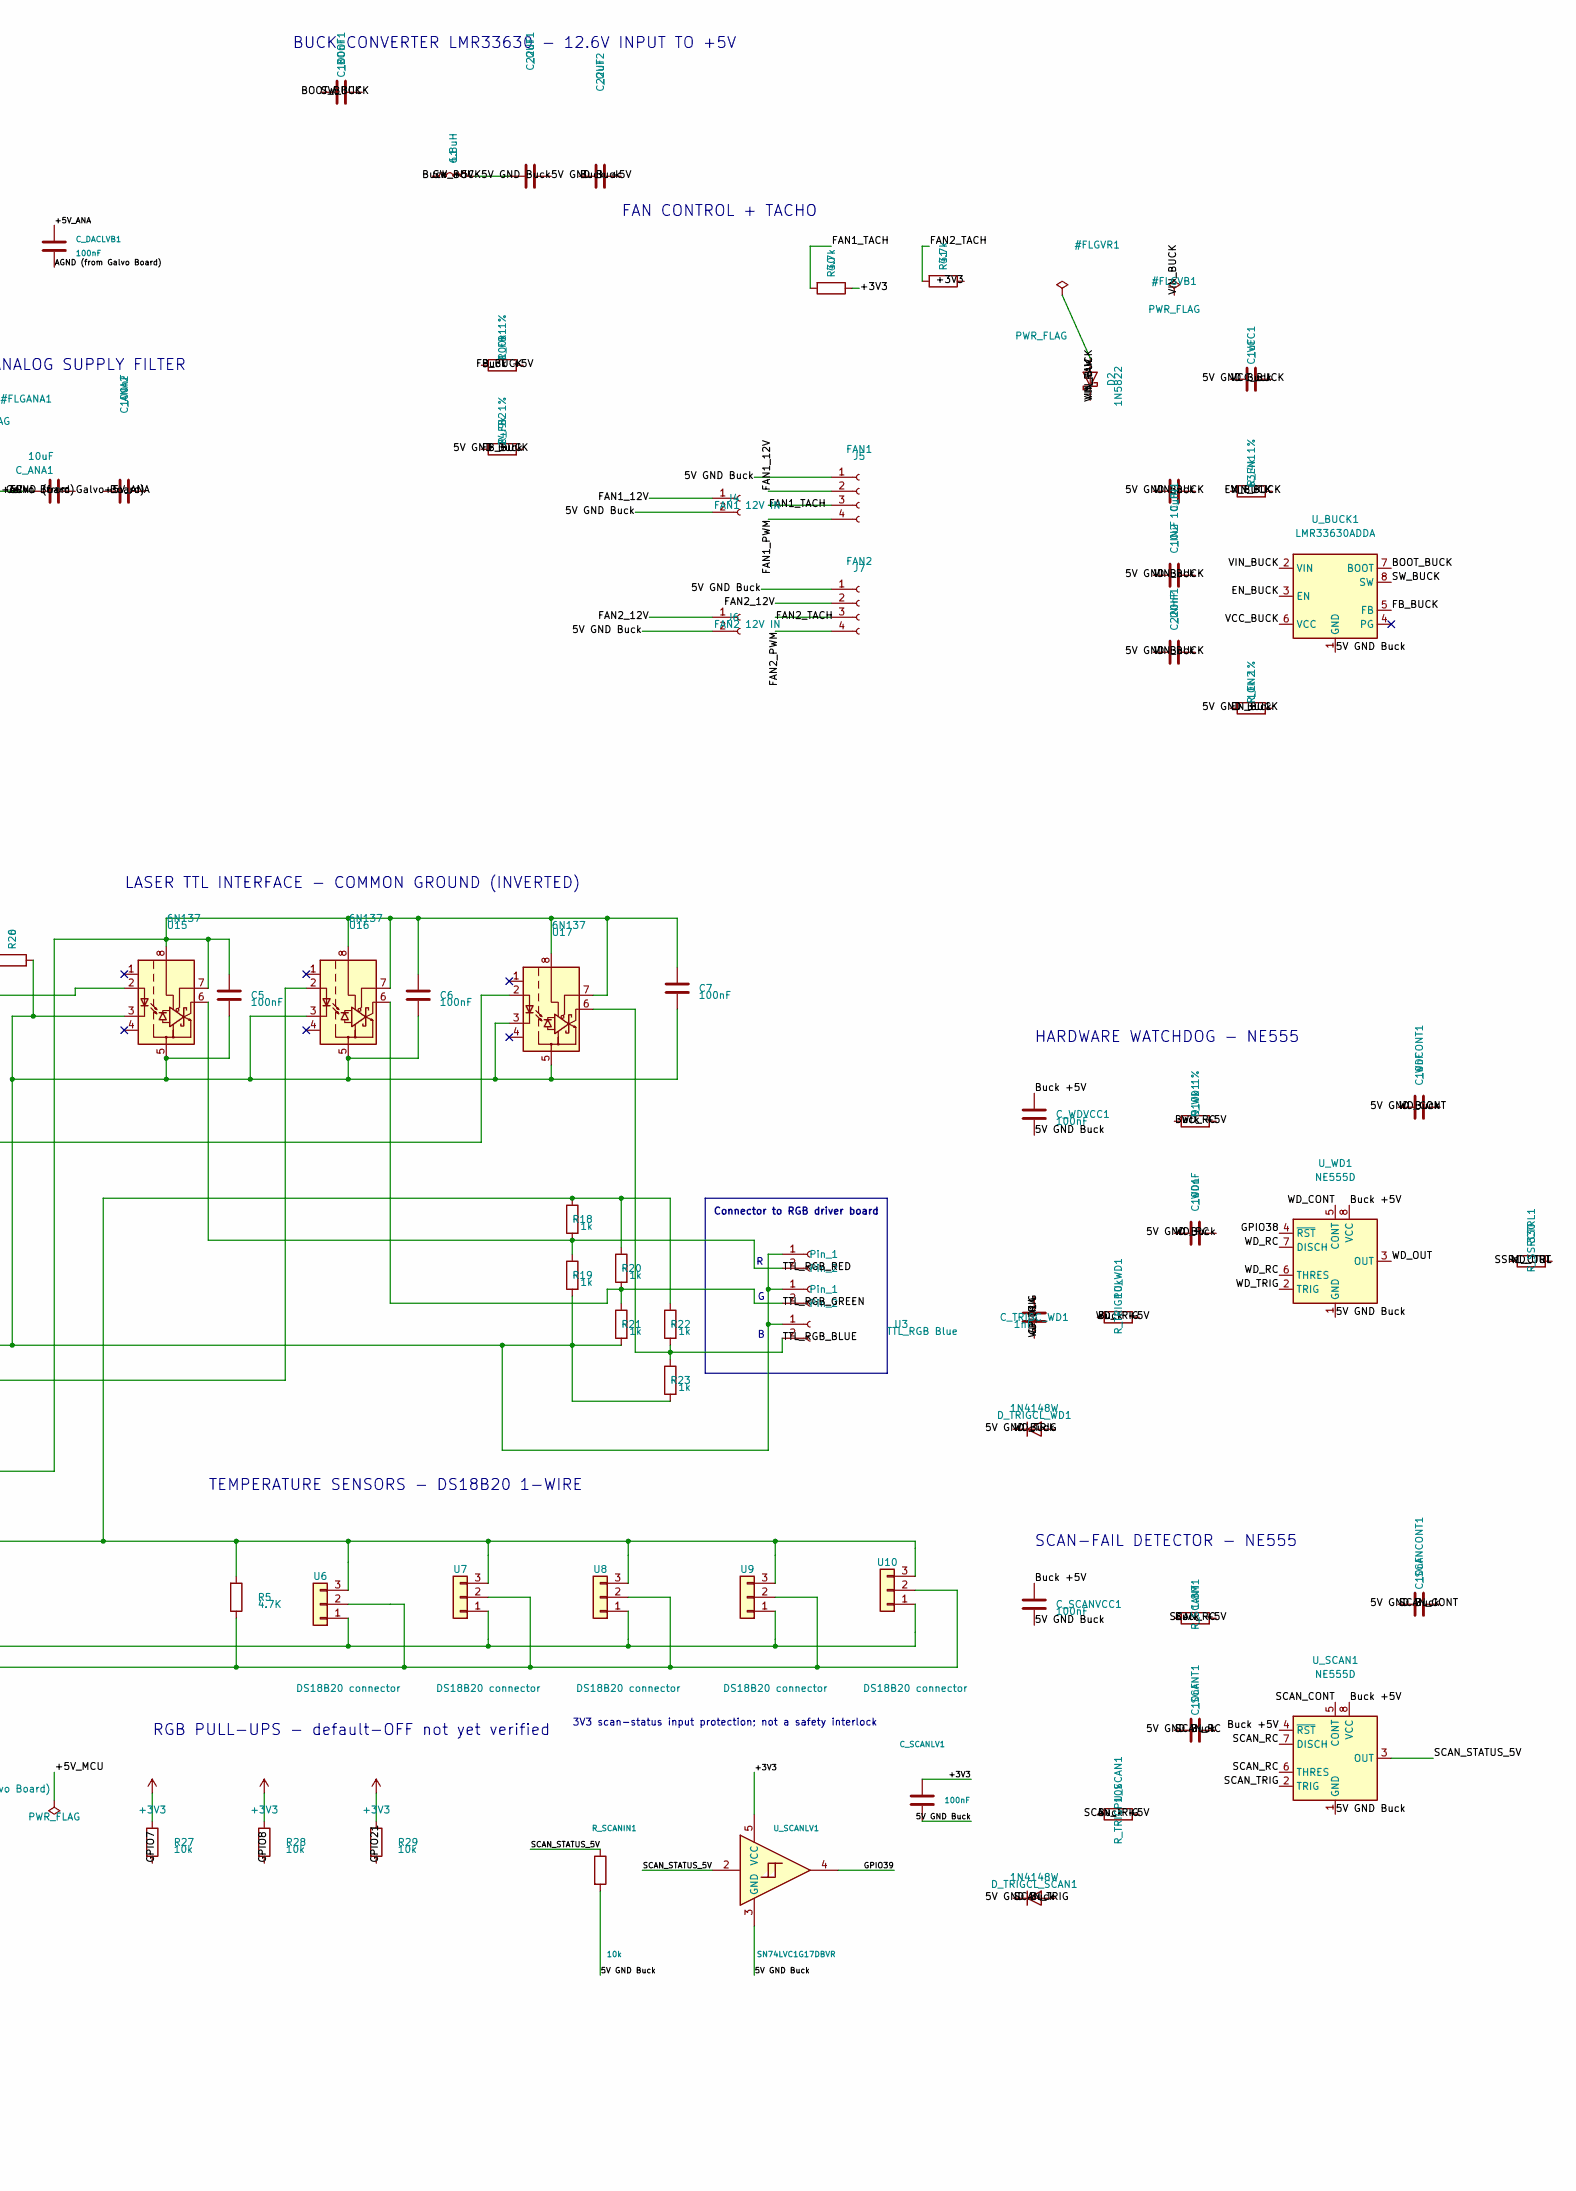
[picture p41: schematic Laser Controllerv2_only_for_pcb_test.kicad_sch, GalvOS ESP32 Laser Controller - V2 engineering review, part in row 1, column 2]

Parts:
C1, C2, C5, C6, C7, C8: 100nF; C_1206_3216Metric
C3, C4: 1nF; C_1206_3216Metric
C9: 100nF; C_1206_3216Metric; Voltage 50V; Tolerance 10%
C_ANA1: 10uF; C_0805_2012Metric
C_ANA2: 100nF; C_1206_3216Metric
C_BOOT1: 100nF; C_1206_3216Metric; Voltage 16V; Tolerance 10%
C_DACLVA1: 100nF; C_1206_3216Metric; Voltage 50V; Tolerance 10%
C_DACLVB1: 100nF; C_1206_3216Metric; Voltage 50V; Tolerance 10%
C_DMXLV1: 100nF; C_1206_3216Metric; Voltage 50V; Tolerance 10%
C_IN1, C_IN2: 10uF; C_1210_3225Metric
C_INHF1: 220nF; C_1206_3216Metric; Voltage 50V; Tolerance 10%
C_OUT1, C_OUT2: 22uF; C_1206_3216Metric
C_SCANCONT1: 10nF; C_1206_3216Metric
C_SCANLV1: 100nF; C_1206_3216Metric; Voltage 50V; Tolerance 10%
C_SCANT1: 10nF; C_1206_3216Metric
C_SCANVCC1: 100nF; C_1206_3216Metric; Voltage 50V; Tolerance 10%
C_SCANX1: 100nF; C_1206_3216Metric
C_SCANY1: 100nF; C_1206_3216Metric
C_TRIGC_WD1: 1nF; C_1206_3216Metric
C_VCC1: 1uF; C_1206_3216Metric; Voltage 16V; Tolerance 10%
C_WD1: 100nF; C_1206_3216Metric
C_WDCONT1: 10nF; C_1206_3216Metric
C_WDVCC1: 100nF; C_1206_3216Metric; Voltage 50V; Tolerance 10%
D1: 1N5819; D_DO-41_SOD81_P10.16mm_Horizontal
D2: 1N5822; D_DO-201AD_P15.24mm_Horizontal
D_TRIGCL_SCAN1: 1N4148W; D_SOD-123; MPN 1N4148W-7-F
D_TRIGCL_WD1: 1N4148W; D_SOD-123; MPN 1N4148W-7-F
FB1: BLM18PG221SN1; L_0603_1608Metric
J1: SD Card Module (6-pin, 2.54mm); PinSocket_1x06_P2.54mm_Vertical
J2: 12.6V IN (BUCK); JST_XH_B2B-XH-A_1x02_P2.50mm_Vertical
J3: PWR IN Galvo; JST_XH_B4B-XH-A_1x04_P2.50mm_Vertical
J4: FAN1 12V IN; JST_XH_B2B-XH-A_1x02_P2.50mm_Vertical
J5: FAN1; Molex_KK-254_AE-6410-04A_1x04_P2.54mm_Vertical
J6: FAN2 12V IN; JST_XH_B2B-XH-A_1x02_P2.50mm_Vertical
J7: FAN2; Molex_KK-254_AE-6410-04A_1x04_P2.54mm_Vertical
J_DMX1: DMX MAX485; JST_XH_B4B-XH-A_1x04_P2.50mm_Vertical
J_ESTOP1: E-STOP; JST_XH_B2B-XH-A_1x02_P2.50mm_Vertical
J_SSR1: SSR1 CTRL; JST_XH_B2B-XH-A_1x02_P2.50mm_Vertical
L1: 6.8uH; L_Sunlord_MWSA1204S-6R8
R1, R2, R4: 220; R_1206_3216Metric
R3: 10K; R_1206_3216Metric
R5: 4.7K; R_1206_3216Metric
R6, R11, R13, R16: 100; R_1206_3216Metric
R7, R10, R14, R15, R27, R28, R29: 10k; R_1206_3216Metric
R9, R12, R17, R25: 22k; R_1206_3216Metric
R18, R19, R20, R21, R22, R23: 1k; R_1206_3216Metric
R26: 0; R_1206_3216Metric
R30, R31: 4.7k; R_1206_3216Metric
R_DACCLR1: 22; R_1206_3216Metric; Tolerance 1%
R_DACCLRA1: 10k; R_1206_3216Metric; Tolerance 1%
R_DACDIN1: 22; R_1206_3216Metric; Tolerance 1%
R_DACDINA1: 10k; R_1206_3216Metric; Tolerance 1%
R_DACDINB1: 10k; R_1206_3216Metric; Tolerance 1%
R_DACSCLK1: 22; R_1206_3216Metric; Tolerance 1%
R_DACSCLKA1: 10k; R_1206_3216Metric; Tolerance 1%
R_DACSCLKB1: 10k; R_1206_3216Metric; Tolerance 1%
R_DACSYNC1: 22; R_1206_3216Metric; Tolerance 1%
R_DACSYNCA1: 10k; R_1206_3216Metric; Tolerance 1%
R_DACSYNCB1: 10k; R_1206_3216Metric; Tolerance 1%
R_DACUNUSED1: 10k; R_1206_3216Metric; Tolerance 1%
R_DMXIN1: 10k; R_1206_3216Metric; Tolerance 1%
R_EN1: 63.4k 1%; R_1206_3216Metric
R_EN2: 10k 1%; R_1206_3216Metric
R_FB1: 100k 1%; R_1206_3216Metric; Tolerance 1%
R_FB2: 24.9k 1%; R_1206_3216Metric; Tolerance 1%
R_SCANIN1: 10k; R_1206_3216Metric; Tolerance 1%
R_SCANT1: 1.8M; R_1206_3216Metric
R_SSRCTRL1: 330; R_1206_3216Metric
R_TRIGPU_SCAN1: 10k; R_1206_3216Metric
R_TRIGPU_WD1: 10k; R_1206_3216Metric
R_WD1: 910k 1%; R_1206_3216Metric
U1: ESP32-S3-N16R8-DevKit; XCVR_ESP32-S3-N16R8-DevKit
U2: DAC8562SDGST; DGS10
U3: TTL_RGB Blue; JST_XH_B2B-XH-A_1x02_P2.50mm_Vertical
U4: TTL_RGB Red; JST_XH_B2B-XH-A_1x02_P2.50mm_Vertical
U5: TTL_RGB Green; JST_XH_B2B-XH-A_1x02_P2.50mm_Vertical
U6, U7, U8, U9, U10: DS18B20 connector; JST_XH_B3B-XH-A_1x03_P2.50mm_Vertical
U12: OPA4134UA_2K5; D14
U13: Galvo Input; JST_XH_B3B-XH-A_1x03_P2.50mm_Vertical
U15, U16, U17: 6N137; DIP-8_W7.62mm
U_BUCK1: LMR33630ADDA; Texas_HSOP-8-1EP_3.9x4.9mm_P1.27mm_ThermalVias
U_DACLV1: SN74LVC8T245PWR; TSSOP-24_4.4x7.8mm_P0.65mm; MPN SN74LVC8T245PWR
U_DMXLV1: SN74LVC1G17DBVR; SOT-23-5; MPN SN74LVC1G17DBVR
U_SCAN1: NE555D; SOIC-8_3.9x4.9mm_P1.27mm
U_SCANLV1: SN74LVC1G17DBVR; SOT-23-5; MPN SN74LVC1G17DBVR
U_WD1: NE555D; SOIC-8_3.9x4.9mm_P1.27mm
X_NODE1: 0; R_1206_3216Metric
Y_NODE1: 0; R_1206_3216Metric

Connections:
5V GND Buck: C5.2, C6.2, C7.2, C_DMXLV1.2, C_IN1.2, C_IN2.2, C_INHF1.2, C_OUT1.2, C_OUT2.2, C_SCANCONT1.2, C_SCANLV1.2, C_SCANT1.2, C_SCANVCC1.2, C_VCC1.2, C_WD1.2, C_WDCONT1.2, C_WDVCC1.2, D_TRIGCL_SCAN1.2 (A), D_TRIGCL_WD1.2 (A), J1.6, J2.2, J4.2, J5.1, J6.2, J7.1, J_DMX1.2, J_ESTOP1.2, J_SSR1.2, R19.2, R21.2, R23.2, R26.2, R_DMXIN1.2, R_EN2.2, R_FB2.2, R_SCANIN1.2, U1.J1_22 (GND), U1.J2_1 (GND), U1.J2_21 (GND), U1.J2_22 (GND), U3.1, U4.1, U5.1, U6.1, U7.1, U8.1, U9.1, U10.1, U15.3 (C), U15.5 (GND), U16.3 (C), U16.5 (GND), U17.3 (C), U17.5 (GND), U_BUCK1.1 (GND), U_BUCK1.9 (GND), U_DMXLV1.3 (GND), U_SCAN1.1 (GND), U_SCANLV1.3 (GND), U_WD1.1 (GND)
+3V3: C_DACLVA1.1, C_DMXLV1.1, C_SCANLV1.1, J1.1, R5.2, R18.1, R20.1, R22.1, R27.1, R28.1, R29.1, R30.1, R31.1, R_DACCLRA1.1, R_DACSYNCA1.1, U1.J1_1 (3V3), U1.J1_2 (3V3), U6.3, U7.3, U8.3, U9.3, U10.3, U_DACLV1.1 (V_{CCA}), U_DACLV1.2 (DIR), U_DMXLV1.5 (VCC), U_SCANLV1.5 (VCC)
+15V: C8.1, J3.1, U12.4 (V+)
-15V: C9.1, J3.3, J3.4, U12.11 (V-)
/+5V_ANA: C1.1, C_ANA1.1, C_ANA2.1, C_DACLVB1.1, FB1.2, R3.2, R_DACSYNCB1.1, U2.9 (AVDD), U_DACLV1.23 (V_{CCB}), U_DACLV1.24 (V_{CCB})
/+5V_MCU: D1.1 (K), U1.J1_21 (5V0)
/BOOT_BUCK: C_BOOT1.2, U_BUCK1.7 (BOOT)
/DAC_CLR_3V3: R_DACCLRA1.2, U1.J1_19 (GPIO13), U_DACLV1.6 (A4)
/DAC_CLR_5V: R3.1, R_DACCLR1.1, U2.5 (CLR)
/DAC_DIN_3V3: R_DACDINA1.1, U1.J1_17 (GPIO11), U_DACLV1.4 (A2)
/DAC_DIN_5V: R_DACDIN1.1, R_DACDINB1.1, U2.8 (DIN)
/DAC_SCLK_3V3: R_DACSCLKA1.1, U1.J1_18 (GPIO12), U_DACLV1.3 (A1)
/DAC_SCLK_5V: R_DACSCLK1.1, R_DACSCLKB1.1, U2.7 (SCLK)
/DAC_SYNC_3V3: R_DACSYNCA1.2, U1.J1_16 (GPIO10), U_DACLV1.5 (A3)
/DAC_SYNC_5V: R_DACSYNC1.1, R_DACSYNCB1.2, U2.6 (SYNC)
/DAC_UNUSED: R_DACUNUSED1.1, U_DACLV1.7 (A5), U_DACLV1.8 (A6), U_DACLV1.9 (A7), U_DACLV1.10 (A8)
/DMX_RO_5V: J_DMX1.3, R_DMXIN1.1, U_DMXLV1.2
/EN_BUCK: R_EN1.2, R_EN2.1, U_BUCK1.3 (EN)
/FAN1_12V: J4.1, J5.2
/FAN1_PWM: J5.4, U1.J1_9 (GPIO16)
/FAN1_TACH: J5.3, R30.2, U1.J2_5 (GPIO2)
/FAN2_12V: J6.1, J7.2
/FAN2_PWM: J7.4, U1.J1_10 (GPIO17)
/FAN2_TACH: J7.3, R31.2, U1.J1_15 (GPIO9)
/FB_BUCK: R_FB1.2, R_FB2.1, U_BUCK1.5 (FB)
/GPIO4: U1.J1_4 (GPIO4), U_DMXLV1.4
/GPIO7: R1.1, R27.2, U1.J1_7 (GPIO7)
/GPIO8: R2.1, R28.2, U1.J1_12 (GPIO8)
/GPIO14: C_TRIGC_WD1.1, U1.J1_20 (GPIO14)
/GPIO21: R4.1, R29.2, U1.J2_18 (GPIO21)
/GPIO38: U1.J2_10 (GPIO38), U_WD1.4 (~RST)
/GPIO39: U1.J2_9 (GPIO39), U_SCANLV1.4
/GPIO47: J_ESTOP1.1, U1.J2_17 (GPIO47)
/SCAN_CONT: C_SCANCONT1.1, U_SCAN1.5 (CONT)
/SCAN_RC: C_SCANT1.1, R_SCANT1.2, U_SCAN1.6 (THRES), U_SCAN1.7 (DISCH)
/SCAN_STATUS_5V: R_SCANIN1.1, U_SCAN1.3 (OUT), U_SCANLV1.2
/SCAN_TRIG: C_SCANX1.1, C_SCANY1.1, D_TRIGCL_SCAN1.1 (K), R_TRIGPU_SCAN1.2, U_SCAN1.2 (TRIG)
/SD_CS: J1.2, U1.J2_6 (GPIO42)
/SD_MISO: J1.5, U1.J2_4 (GPIO1)
/SD_MOSI: J1.3, U1.J1_6 (GPIO6)
/SD_SCK: J1.4, U1.J1_5 (GPIO5)
/SSR1_CTRL: J_SSR1.1, R_SSRCTRL1.2
/SW_BUCK: C_BOOT1.1, L1.1, U_BUCK1.8 (SW)
/TTL_RGB_BLUE: R22.2, R23.1, U3.2, U17.6 (VO)
/TTL_RGB_GREEN: R20.2, R21.1, U5.2, U16.6 (VO)
/TTL_RGB_RED: R18.2, R19.1, U4.2, U15.6 (VO)
/VCC_BUCK: C_VCC1.1, U_BUCK1.6 (VCC)
/VIN_BUCK: C_IN1.1, C_IN2.1, C_INHF1.1, D2.1 (K), R_EN1.1, U_BUCK1.2 (VIN)
/VREF_BUF: R10.2, R15.2, U12.8 (OUT_C), U12.9 (-IN_C)
/WD_CONT: C_WDCONT1.1, U_WD1.5 (CONT)
/WD_OUT: R_SSRCTRL1.1, U_WD1.3 (OUT)
/WD_RC: C_WD1.1, R_WD1.2, U_WD1.6 (THRES), U_WD1.7 (DISCH)
/WD_TRIG: C_TRIGC_WD1.2, D_TRIGCL_WD1.1 (K), R_TRIGPU_WD1.2, U_WD1.2 (TRIG)
AGND (from Galvo Board): C1.2, C2.2, C3.2, C4.2, C8.2, C9.2, C_ANA1.2, C_ANA2.2, C_DACLVA1.2, C_DACLVB1.2, J3.2, R9.2, R25.2, R26.1, R_DACDINA1.2, R_DACDINB1.2, R_DACSCLKA1.2, R_DACSCLKB1.2, R_DACUNUSED1.2, U2.3 (GND), U2.4 (LDAC), U12.12 (+IN_D), U13.1, U_DACLV1.11 (GND), U_DACLV1.12 (GND), U_DACLV1.13 (GND), U_DACLV1.22 (~OE)
Buck +5V: C5.1, C6.1, C7.1, C_OUT1.1, C_OUT2.1, C_SCANVCC1.1, C_WDVCC1.1, D1.2 (A), FB1.1, J_DMX1.1, L1.2, R_FB1.1, R_SCANT1.1, R_TRIGPU_SCAN1.1, R_TRIGPU_WD1.1, R_WD1.1, U15.7 (EN), U15.8 (VCC), U16.7 (EN), U16.8 (VCC), U17.7 (EN), U17.8 (VCC), U_SCAN1.4 (~RST), U_SCAN1.8 (VCC), U_WD1.8 (VCC)
unnamed: C3.1, R11.1, X_NODE1.1
unnamed: C4.1, R13.1, Y_NODE1.1
unnamed: C_SCANX1.2, R7.2, X_NODE1.2
unnamed: C_SCANY1.2, R14.2, Y_NODE1.2
unnamed: R5.1, U1.J1_11 (GPIO18), U6.2, U7.2, U8.2, U9.2, U10.2
unnamed: R11.2, U2.1 (VOUTA)
unnamed: R13.2, U2.2 (VOUTB)
unnamed: R9.1, R10.1, U12.3 (+IN_A)
unnamed: R15.1, R25.1, U12.5 (+IN_B)
unnamed: C2.1, U2.10 (VREFINNREFOUT), U12.10 (+IN_C)
unnamed: R7.1, R12.2, U12.2 (-IN_A)
unnamed: R14.1, R17.1, U12.6 (-IN_B)
unnamed: U12.13 (-IN_D), U12.14 (OUT_D)
unnamed: R6.1, R12.1, U12.1 (OUT_A)
unnamed: R16.1, R17.2, U12.7 (OUT_B)
unnamed: R6.2, U13.2
unnamed: R16.2, U13.3
unnamed: R1.2, U15.2 (A)
unnamed: R2.2, U16.2 (A)
unnamed: R4.2, U17.2 (A)
unnamed: R_DACSCLK1.2, U_DACLV1.21 (B1)
unnamed: R_DACDIN1.2, U_DACLV1.20 (B2)
unnamed: R_DACSYNC1.2, U_DACLV1.19 (B3)
unnamed: R_DACCLR1.2, U_DACLV1.18 (B4)
VIN_RAW: D2.2 (A), J2.1

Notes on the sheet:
Connector to RGB driver board
SUPPLY INLETS
Connector to Galvo Board
GND
RGB PULL-UPS - default-OFF not yet verified
RAIL FLAGS (ERC)
3V3 DMX input protection; no galvanic isolation
GALVO ANALOG OUTPUT - OPA4134
DAC8562 - DUAL 16-BIT DAC (SPI2)
+5V ANALOG SUPPLY FILTER
BUCK CONVERTER LMR33630 - 12.6V INPUT TO +5V
FAN CONTROL + TACHO
ESP32-S3-N16R8 CONTROLLER
SD CARD (SPI3)
LASER TTL INTERFACE - COMMON GROUND (INVERTED)
HARDWARE WATCHDOG - NE555
SCAN-FAIL DETECTOR - NE555
TEMPERATURE SENSORS - DS18B20 1-WIRE
EXTERNAL INTERFACES - E-STOP / DMX / SSR
3V3 scan-status input protection; not a safety interlock
DAC INPUT DEFAULTS / 3V3
DAC OUTPUT DEFAULTS / 5V

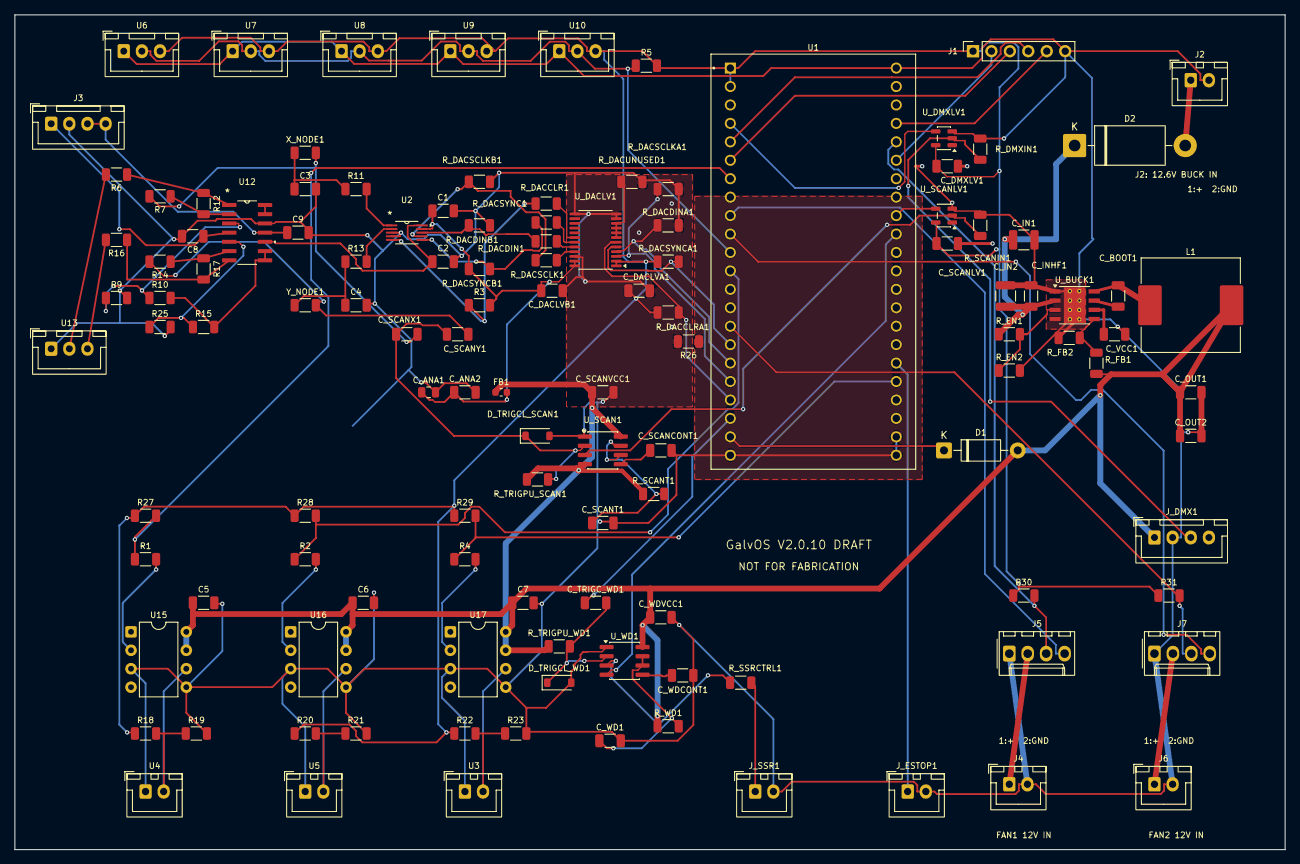
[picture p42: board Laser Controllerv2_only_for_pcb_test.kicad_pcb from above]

Board: 2 copper layers, 175.0 x 115.0 mm, 122 parts (0 on the bottom side), 80 nets.

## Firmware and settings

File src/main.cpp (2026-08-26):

/**
 * main.cpp -- GalvOS - Custom Galvo Laser Show Controller Firmware (WebUI-Focus)
 *
 * Core 0: WiFi, WebUI, Art-Net, sACN, Ether Dream, Helios (net), OSC, Safety, DMX
 * Core 1: Galvo-Timer-ISR + Pattern-Engine
 */

#include <Arduino.h>
#include <WiFi.h>
#include <Preferences.h>
#include <LittleFS.h>
#include <esp_log.h>
#include <esp_task_wdt.h>   // WDT-control
#include <esp_wifi.h>       // esp_wifi_get/set_config -- SAE PWE (WPA3) compat, see wifiBeginWpa3Compat()
#include <new>                        // placement new (gPaint -> PSRAM)
#include <soc/soc_memory_layout.h>    // esp_ptr_external_ram
#include "util/mem_registry.h"
#include "config.h"
#include "pinmap.h"
#include "safety/safety.h"
#include "output/galvo_out.h"
#include "control/dmx_in.h"
#include "bpm_clock.h"
#include "patterns/pattern_engine.h"
#include "patterns/point_optimizer.h"
#include "storage/sd_card.h"
#include "control/encoder.h"
#include "mutex.h"
#include <esp_system.h>
#include "net/ota_update.h"
#include "net/etherdream.h"
#include "net/helios_net.h"
#include "net/osc_in.h"
#include "net/sacn_in.h"
#include "storage/playlist.h"
#include "sequencer.h"
#include "ilda/ilda_player.h"
#include "net/artnet_in.h"
#include "net/ntp_client.h"
#include "net/wifi_watchdog.h"
#include "net/web_ui.h"
#include "net/etherdream.h"
#include "sensors/temp_monitor.h"
#include "util/log_buffer.h"
#include "util/cpu_monitor.h"
#include "util/stack_mon.h"

// Global data -- must be defined exactly once here
RuntimeConfig    gConfig;
RuntimeState     gState;
SafetyConfig     gSafety;
PlaylistConfig   gPlaylist;
SequencerConfig  gSequencer;
WebOverride      gOverride;
LivePresetControls gLivePreset;
TextConfig       gTextConfig;
CurveConfig      gCurves;
ProjectionConfig gProjection;
OptimizerLiveConfig gOptimizerProfiles[OPT_PROFILE_COUNT];  // one per PresetClass
OptimizerLiveConfig gOptimizerConfig;          // live copy of active profile
volatile uint8_t    gActiveOptimizerProfile = OPT_PROFILE_VECTOR;
optimizer::AffineTransform optimizer::gLiveTransform;  // Phase 3: live Z-rot + move affine, published per-frame by pattern_engine
volatile uint32_t   gPatternCacheGen = 0; // Phase 2 static-preset cache invalidation
ZoneConfig       gZone;                 // touch-defined projection zone
// gWarp is defined in warpGrid.cpp (not here) -- that keeps warpGrid.cpp a
// self-contained translation unit the native/host optimizer test build can
// link on its own, same as point_optimizer.cpp itself. See platformio.ini's
// [env:native] build_src_filter.
// Paint canvas (~9 KB) lives in PSRAM: placement-new at static-init time
// (PSRAM heap is registered before global ctors via CONFIG_SPIRAM_BOOT_INIT).
// DRAM fallback keeps PSRAM-less debug setups alive.
static PaintConfig* allocPaintConfig() {
    void* p = ps_malloc(sizeof(PaintConfig));
    if (!p) p = malloc(sizeof(PaintConfig));
    return new (p) PaintConfig();
}
PaintConfig&     gPaint = *allocPaintConfig();  // paint-by-finger canvas
WeldConfig       gWeld;                          // laser welding effect (RAM-only, small struct -> plain DRAM)
volatile bool    gDebugNoHW = false;
DebugOptDisable  gDebugOptDisable;                 // per-stage optimizer kill switches (RAM-only, see config.h)

static const char* TAG = "main";
static Preferences s_prefs;

static void loadConfig() {
    s_prefs.begin("laser", true);
    gConfig.dmx_address     = s_prefs.getUShort("dmx_addr",  DEFAULT_DMX_ADDRESS);
    gConfig.artnet_universe = s_prefs.getUShort("artnet_uni",DEFAULT_DMX_UNIVERSE);
    gConfig.galvo_x_offset  = s_prefs.getShort("xoff", 0);
    gConfig.galvo_y_offset  = s_prefs.getShort("yoff", 0);
    gConfig.galvo_x_gain    = s_prefs.getShort("xgain", 32767);
    gConfig.galvo_y_gain    = s_prefs.getShort("ygain", 32767);
    gConfig.dac_limit_min   = s_prefs.getUShort("dac_lim_lo", 0x0666);
    gConfig.dac_limit_max   = s_prefs.getUShort("dac_lim_hi", 0xF999);
    gConfig.outputScale     = s_prefs.getFloat("out_scale", 0.91f);
    gConfig.swap_xy         = s_prefs.getBool("swap", false);
    gConfig.invert_x        = s_prefs.getBool("invx", false);
    gConfig.invert_y        = s_prefs.getBool("invy", false);
    gConfig.gain_r          = s_prefs.getUChar("gain_r", 115);  // FIX: R=1W
    gConfig.gain_g          = s_prefs.getUChar("gain_g",  43);  // FIX: G=1W
    gConfig.gain_b          = s_prefs.getUChar("gain_b", 255);  // FIX: B=3W
    gConfig.thresh_r        = s_prefs.getUChar("thresh_r", 143);
    gConfig.thresh_g        = s_prefs.getUChar("thresh_g", 144);
    gConfig.thresh_b        = s_prefs.getUChar("thresh_b", 169);
    gConfig.gamma_enable    = s_prefs.getBool ("gamma_en", true);
    gConfig.osc_enabled        = s_prefs.getBool("osc_en",    true);
    gConfig.sacn_enabled       = s_prefs.getBool("sacn_en",   true);
    gConfig.helios_net_enabled = s_prefs.getBool("helios_en", true);
    gConfig.artnet_enabled     = s_prefs.getBool("artnet_en", true);
    gConfig.etherdream_enabled = s_prefs.getBool("edream_en", true);
    gConfig.debug_log_dmx        = s_prefs.getBool("dbg_dmx",    false);
    gConfig.debug_log_artnet     = s_prefs.getBool("dbg_artnet", false);
    gConfig.debug_log_etherdream = s_prefs.getBool("dbg_edream", false);
    gConfig.debug_log_helios_net = s_prefs.getBool("dbg_helios", false);
    gConfig.debug_log_osc        = s_prefs.getBool("dbg_osc",    false);
    gConfig.debug_log_sacn       = s_prefs.getBool("dbg_sacn",   false);
    // NVS suffixes are pinned to the profile index, not to its name, so the
    // v1 profile set (Simple/Curves/3D/Scenes/Solar) migrates in place onto
    // the renamed profiles instead of resetting. "_w" is new (Waves) and
    // falls back to compile-time defaults on first boot.
    static const struct { const char* sfx; uint8_t idx; } PROF_MAP[] = {
        { "_s",   OPT_PROFILE_VECTOR      },  // was Simple
        { "_c",   OPT_PROFILE_SMOOTH      },  // was Curves
        { "_w",   OPT_PROFILE_WAVES       },  // new
        { "_3",   OPT_PROFILE_WIREFRAME   },  // was ThreeD
        { "_sol", OPT_PROFILE_MULTIOBJECT },  // was Solar
        { "_sc",  OPT_PROFILE_PARTICLES   },  // was Scenes
        { "_tr",  OPT_PROFILE_TRAILS      },  // new: Shooting Stars et al.
        { "_txt", OPT_PROFILE_TEXT        },  // new: Text renderer
    };
    for (auto& pm : PROF_MAP) {
        OptimizerLiveConfig& p = gOptimizerProfiles[pm.idx];
        // Per-profile tuned fallbacks (see OPT_PROFILE_DEFAULTS in config.h).
        // Stored NVS values still win; this only changes what an UNSET profile
        // parameter falls back to, so the six profiles no longer all boot
        // from the same generic OPT_DEFAULT_* values.
        const OptimizerProfileDefaults& pd = OPT_PROFILE_DEFAULTS[pm.idx];
        char k[16];
        #define LOAD_F(b,f,d)  snprintf(k,sizeof(k),"%s%s",b,pm.sfx); p.f=s_prefs.getFloat(k,d)
        #define LOAD_U(b,f,d)  snprintf(k,sizeof(k),"%s%s",b,pm.sfx); p.f=s_prefs.getUChar(k,d)
        #define LOAD_S(b,f,d)  snprintf(k,sizeof(k),"%s%s",b,pm.sfx); p.f=s_prefs.getUShort(k,d)
        #define LOAD_B(b,f,d)  snprintf(k,sizeof(k),"%s%s",b,pm.sfx); p.f=s_prefs.getBool(k,d)
        LOAD_F("opt_cad",   corner_angle_deg,             pd.corner_angle_deg);
        LOAD_U("opt_mincp", min_corner_pts,               pd.min_corner_pts);
        LOAD_U("opt_maxcp", max_corner_pts,               pd.max_corner_pts);
        LOAD_F("opt_ppu",   pts_per_1000_units,           pd.pts_per_1000_units);
        LOAD_U("opt_blank", blank_samples,                pd.blank_samples);
        LOAD_S("opt_maxppf",max_pts_per_frame,            pd.max_pts_per_frame);
        LOAD_U("opt_minbl", min_blank_samples,            pd.min_blank_samples);
        LOAD_F("opt_blppu", blank_pts_per_1000_units,     pd.blank_pts_per_1000_units);
        LOAD_U("opt_minip", min_interior_pts_per_segment, pd.min_interior_pts_per_segment);
        LOAD_U("opt_s1tgt", stage1_blank_target,          pd.stage1_blank_target);
        LOAD_B("opt_rsen",  resample_enabled,             OPT_DEFAULT_RESAMPLE_ENABLED);
        LOAD_F("opt_rssp",  resample_spacing_units,       OPT_DEFAULT_RESAMPLE_SPACING_UNITS);
        LOAD_B("opt_cven",  curvature_resample_enabled,   OPT_DEFAULT_CURVATURE_RESAMPLE_ENABLED);
        LOAD_F("opt_cvgn",  curvature_gain,               OPT_DEFAULT_CURVATURE_GAIN);
        LOAD_F("opt_cvmn",  min_spacing_units,            OPT_DEFAULT_MIN_SPACING_UNITS);
        LOAD_F("opt_cvmx",  max_spacing_units,            OPT_DEFAULT_MAX_SPACING_UNITS);
        LOAD_B("opt_rngen", ringing_comp_enabled,         OPT_DEFAULT_RINGING_COMP_ENABLED);
        LOAD_F("opt_rngfq", ring_freq_hz,                 OPT_DEFAULT_RING_FREQ_HZ);
        LOAD_F("opt_rngdr", ring_damping_ratio,           OPT_DEFAULT_RING_DAMPING_RATIO);
        LOAD_B("opt_jten",  jitter_enabled,               OPT_DEFAULT_JITTER_ENABLED);
        LOAD_F("opt_jtam",  jitter_amount_units,          OPT_DEFAULT_JITTER_AMOUNT_UNITS);
        LOAD_B("opt_vcen",  vel_clamp_enabled,            OPT_DEFAULT_VEL_CLAMP_ENABLED);
        LOAD_F("opt_vcstp", max_step_units,               OPT_DEFAULT_MAX_STEP_UNITS);
        LOAD_B("opt_acen",  accel_clamp_enabled,          OPT_DEFAULT_ACCEL_CLAMP_ENABLED);
        LOAD_F("opt_acmax", max_accel_units,              OPT_DEFAULT_MAX_ACCEL_UNITS);
        LOAD_B("opt_reord", reorder_segments,             OPT_DEFAULT_REORDER_SEGMENTS);
        LOAD_B("opt_ro2op", reorder_2opt,                 OPT_DEFAULT_REORDER_2OPT);
        #undef LOAD_F
        #undef LOAD_U
        #undef LOAD_S
        #undef LOAD_B
    }
    syncOptimizerConfig();
    gSafety.temp_warn_c     = s_prefs.getUChar("t_warn",  45);
    gSafety.temp_reduce_c   = s_prefs.getUChar("t_red",   55);
    gSafety.temp_shutdown_c = s_prefs.getUChar("t_shut",  70);
    gSafety.fan_min_pct     = s_prefs.getUChar("fan_min", 15);
    gSafety.fan_auto        = s_prefs.getBool ("fan_auto",true);
    s_prefs.getString("ssid", gConfig.wifi_ssid, sizeof(gConfig.wifi_ssid));
    s_prefs.getString("pass", gConfig.wifi_pass, sizeof(gConfig.wifi_pass));
    s_prefs.getString("host", gConfig.hostname,  sizeof(gConfig.hostname));
    gConfig.wifi_static = s_prefs.getBool("static_ip", false);
    s_prefs.getString("ip",   gConfig.wifi_ip,   sizeof(gConfig.wifi_ip));
    s_prefs.getString("gw",   gConfig.wifi_gw,   sizeof(gConfig.wifi_gw));
    s_prefs.getString("mask", gConfig.wifi_mask,  sizeof(gConfig.wifi_mask));
    s_prefs.getString("dns",  gConfig.wifi_dns,   sizeof(gConfig.wifi_dns));
    s_prefs.getString("auth_hash", gConfig.auth_hash, sizeof(gConfig.auth_hash));
    gConfig.wifi_watchdog_reboot_enabled  = s_prefs.getBool("gw_wd_en", true);
    gConfig.wifi_watchdog_soft_timeout_ms = s_prefs.getULong("gw_wd_sto", 30000);
    gConfig.wifi_watchdog_timeout_ms      = s_prefs.getULong("gw_wd_to", 300000);

    // Generate unique hostname from last 3 MAC bytes if none stored in NVS
    if (strlen(gConfig.hostname) == 0) {
        uint8_t mac[6];
        WiFi.macAddress(mac);
        snprintf(gConfig.hostname, sizeof(gConfig.hostname),
                 "galvos-%02X%02X%02X", mac[3], mac[4], mac[5]);
    }
    s_prefs.end();
    ESP_LOGI(TAG, "Config loaded. DMX=%u Hostname=%s Auth=%s",
             gConfig.dmx_address, gConfig.hostname,
             strlen(gConfig.auth_hash) ? "custom" : "default ('laser')");
}

// ══════════════════════════════════════════════════════════════
// Hardware panic blanking -- laser off on ANY crash
//
// Called on: Guru Meditation, Double Exception,
// Stack Smash, Hardfault, Brownout, WDT
//
// IRAM_ATTR: runs from RAM -- works even if flash defective/busy
// No FreeRTOS context -- ONLY direct GPIO register access
// ══════════════════════════════════════════════════════════════
#include <esp_private/panic_internal.h>

static void IRAM_ATTR laser_panic_blanking(const char* reason) {
    // Direct GPIO-Register-Manipulation (no Arduino, no FreeRTOS)
    // Works even with a complete stack overflow
    // Inverted logic: HIGH = laser OFF (active-HIGH driver MN-1W5AT)
    gpio_set_level((gpio_num_t)PIN_LASER_R,  1);  // HIGH = laser OFF
    gpio_set_level((gpio_num_t)PIN_LASER_G,  1);
    gpio_set_level((gpio_num_t)PIN_LASER_B,  1);
    gpio_set_level((gpio_num_t)PIN_LASER_EN, 0);  // SSR off
    // Call ESP-IDF default panic handler (prints backtrace + reset)
    // esp_panic_handler(reason);  
    esp_restart();  // safety reboot
}

// Brownout-Callback (registriert in setup)
static void IRAM_ATTR brownout_cb() {
    gpio_set_level((gpio_num_t)PIN_LASER_R,  1);  // HIGH = laser OFF
    gpio_set_level((gpio_num_t)PIN_LASER_G,  1);
    gpio_set_level((gpio_num_t)PIN_LASER_B,  1);
    gpio_set_level((gpio_num_t)PIN_LASER_EN, 0);
}

// ── Task-start helper with error checking ─────────────
static bool startTask(TaskFunction_t fn, const char* name,
                      uint32_t stack, UBaseType_t prio, BaseType_t core = 0) {
    TaskHandle_t h = nullptr;
    BaseType_t r = xTaskCreatePinnedToCore(
        fn, name, stack, nullptr, prio, &h, core);
    if (r != pdPASS || !h) {
        ESP_LOGE("main", "TASK FAILED: %s (Heap=%u)", name, ESP.getFreeHeap());
        LOG_E(logbuf::CAT_SYSTEM, "Task failed: %s", name);
        return false;
    }
    ESP_LOGI("main", "Task OK: %-10s p=%u c=%d s=%u", name, prio, core, stack);
    stackMon::watch(h, name, stack);
    return true;
}

// Decoded label for the last reset cause. Logged once at boot: a
// ESP_RST_BROWNOUT here is hard proof that the module's 3V3 rail actually
// collapsed below the brownout detector's threshold (~2.5V on the ESP32-S3).
// Note the converse does NOT hold -- the RF front-end (VDD3P3_RF) can lose
// lock on a dip far shallower than the detector's trip point, so a clean
// ESP_RST_POWERON does not clear a marginal supply of suspicion.
static const char* resetReasonStr(esp_reset_reason_t r) {
    switch (r) {
        case ESP_RST_POWERON:   return "POWERON";
        case ESP_RST_EXT:       return "EXT_PIN";
        case ESP_RST_SW:        return "SW_RESTART";
        case ESP_RST_PANIC:     return "PANIC";
        case ESP_RST_INT_WDT:   return "INT_WDT";
        case ESP_RST_TASK_WDT:  return "TASK_WDT";
        case ESP_RST_WDT:       return "OTHER_WDT";
        case ESP_RST_DEEPSLEEP: return "DEEPSLEEP";
        case ESP_RST_BROWNOUT:  return "BROWNOUT";
        case ESP_RST_SDIO:      return "SDIO";
        default:                return "UNKNOWN";
    }
}

// Short human-readable label for wifi_auth_mode_t -- used only in log lines
// below, to make an AP-side auth-mode flip (e.g. WPA2<->WPA3-transition)
// visible without having to decode the numeric enum by hand.
static const char* authModeStr(wifi_auth_mode_t m) {
    switch (m) {
        case WIFI_AUTH_OPEN:            return "OPEN";
        case WIFI_AUTH_WEP:             return "WEP";
        case WIFI_AUTH_WPA_PSK:         return "WPA_PSK";
        case WIFI_AUTH_WPA2_PSK:        return "WPA2_PSK";
        case WIFI_AUTH_WPA_WPA2_PSK:    return "WPA_WPA2_PSK";
        case WIFI_AUTH_WPA2_ENTERPRISE: return "WPA2_ENTERPRISE";
        case WIFI_AUTH_WPA3_PSK:        return "WPA3_PSK";
        case WIFI_AUTH_WPA2_WPA3_PSK:   return "WPA2_WPA3_PSK";
        case WIFI_AUTH_WAPI_PSK:        return "WAPI_PSK";
        default:                        return "UNKNOWN";
    }
}

// Start a STA connection with SAE PWE derivation explicitly set to "both"
// (hunt-and-peck + hash-to-element). Arduino's WiFi.begin() always leaves
// wifi_sta_config_t::sae_pwe_h2e at 0 (WPA3_SAE_PWE_UNSPECIFIED), which the
// IDF WiFi driver then treats as hunt-and-peck-only -- some WPA2/WPA3-
// transition APs (observed: Ubiquiti UniFi, default WPA2/WPA3 mode) only
// negotiate H2E and simply never complete the SAE exchange against a
// hunt-and-peck-only client. That surfaces as a generic reason=15
// (4WAY_HANDSHAKE_TIMEOUT) with no WPA3-specific signal in the disconnect
// reason -- confirmed on this hardware by the fact a pure-WPA2 AP (iPhone
// hotspot with "Maximize Compatibility" on) connects instantly while the
// same AP's default WPA2/WPA3-transition mode times out every attempt.
// Reuses WiFi.begin(..., connect=false) for the ssid/pass/threshold
// bookkeeping (keeps Arduino's own validation + WiFiSTAClass state in sync),
// then patches just this one field before kicking off the connection
// ourselves -- avoids reimplementing the rest of WiFiSTAClass::begin().
static void wifiBeginWpa3Compat(const char* ssid, const char* pass,
                                 int32_t channel = 0, const uint8_t* bssid = nullptr) {
    WiFi.begin(ssid, pass, channel, bssid, /*connect=*/false);
    wifi_config_t conf;
    if (esp_wifi_get_config(WIFI_IF_STA, &conf) == ESP_OK) {
        conf.sta.sae_pwe_h2e = WPA3_SAE_PWE_BOTH;
        esp_wifi_set_config(WIFI_IF_STA, &conf);
    }
    esp_wifi_connect();
}
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
void loop() {
    ota_update::handle();  // Feature 2: OTA handle in loop

    cpu_mon::update();     // update CPU load measurement (internal 500ms rate-limit)
    safety::heartbeat();

    static uint32_t last_print = 0;
    if (millis() - last_print > 10000) {
        // ── System status ──────────────────────────────────────────────
        ESP_LOGI(TAG, "Heap=%u PSRAM=%u pps=%lu src=%d arm=%d",
                 ESP.getFreeHeap(), ESP.getFreePsram(),
                 (unsigned long)gState.points_per_sec,
                 (int)gState.source, (int)gState.laser_armed);

        // ── CPU load ───────────────────────────────────────────────────
        ESP_LOGI(TAG, "CPU  Core0=%u%%  Core1=%u%%",
                 cpu_mon::load0(), cpu_mon::load1());

        // ── Fan + temperatures ─────────────────────────────────────────
        ESP_LOGI(TAG, "Fan  fan1=%u%%  fan2=%u%%",
                 (unsigned)(temp::gTempState.fan1_duty * 100 / 255),
                 (unsigned)(temp::gTempState.fan2_duty * 100 / 255));
        for (uint8_t i = 0; i < temp::NUM_SENSORS; i++) {
            if (temp::gTempState.sensor_ok[i]) {
                ESP_LOGI(TAG, "Temp [%u] %-20s %.1f C%s%s",
                         i, temp::sensor_names[i],
                         temp::gTempState.temp_c[i],
                         temp::gTempState.warn_active[i]  ? " WARN"  : "",
                         temp::gTempState.alert_active[i] ? " ALERT" : "");
            }
        }

        // ── Task stack high-water marks ────────────────────────────────
        // Shows minimum free stack ever seen per task (bytes).
        // If close to 0 -> stack overflow risk!
        static const char* const k_tasks[] = {
            "galvo_out", "pattern", "web_ui", "temp", "dmx_rx", nullptr
        };
        for (int i = 0; k_tasks[i]; i++) {
            TaskHandle_t h = xTaskGetHandle(k_tasks[i]);
            if (h) {
                ESP_LOGI(TAG, "Stack [%-10s] HWM=%u bytes free",
                         k_tasks[i],
                         (unsigned)(uxTaskGetStackHighWaterMark(h) * sizeof(StackType_t)));
            }
        }

        last_print = millis();
    }
    delay(100);
}

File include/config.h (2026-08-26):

#pragma once
#include <atomic>
/**
 * config.h -- runtime configuration and shared data types
 */

#include <Arduino.h>
#include <stdint.h>

// debug mode: Galvo/Laser-Hardware ueberspringen (only ESP32, no Laser)
// Set when /api/debug-mode is enabled -- also persistent via NVS.
extern volatile bool gDebugNoHW;

constexpr uint16_t GALVO_RATE_HZ      = GALVO_SAMPLE_RATE_HZ;
constexpr size_t   PATTERN_POINTS_MAX = 2048;

// Points-Only render mode (pattern_engine.cpp::applyPointsOnlyMode)
constexpr uint8_t  POINTS_MODE_MAX_DOTS  = 50;  // UI slider ceiling
constexpr uint8_t  POINTS_MODE_MIN_DWELL = 3;   // ticks; below this a dot is invisible
constexpr uint8_t  POINTS_MODE_MAX_DWELL = 30;  // ticks; cap so few dots don't hog the whole frame

// Flow Mode (pattern_engine.cpp::applyFlowMode) -- draws a moving trail along
// the already-generated path instead of the whole geometry at once.
constexpr uint8_t  FLOW_MODE_MAX_SEGMENTS = 8;  // simultaneous trails, evenly spaced along the path

// Random Points preset (preset_patterns.cpp::p106)
constexpr uint8_t  RANDOM_PTS_MAX_COUNT = 14;   // UI slider ceiling ("Amount")

// Kaleidoscope effect (pattern_engine.cpp::applyKaleidoscope)
constexpr uint8_t  KALEIDO_SEGMENTS_MAX = 6;   // UI slider ceiling (even only)

// GalvOS v5 Point Optimizer (Pillar 1) -- runtime-tunable via WebUI slider.
// Mirrors optimizer::OptimizerConfig's persisted/tunable fields -- NOT the
// full struct. Two OptimizerConfig fields are deliberately absent here:
// galvo_kpps (set per-call from gProjection.galvo_kpps by configFromLive(),
// not a stored preference) and transform (set per-frame from
// optimizer::gLiveTransform). Per-call frame context (hasPrevPos/prevX/
// prevY/frameBudgetRemaining) isn't a config value at all and has no
// counterpart here either. Kept as a separate struct here (rather than
// including point_optimizer.h) to avoid pulling the optimizer's geometry
// types into every translation unit that already includes config.h.
//
// DEFAULT VALUES: tuned for a 30 kpps output rate (GALVO_SAMPLE_RATE_HZ,
// see platformio.ini). max_pts_per_frame=1010 -> 30000/1010 ~= 30 Hz, a
// mostly flicker-free floor at that rate (see optimize()'s frame-budget
// comment for how frameBudgetRemaining spends this across multi-call
// frames). All OPT_DEFAULT_* macros are the single source of truth;
// point_optimizer.h references them so both structs stay in sync
// automatically.
#define OPT_DEFAULT_CORNER_ANGLE_DEG            25.0f
#define OPT_DEFAULT_MIN_CORNER_PTS              2
#define OPT_DEFAULT_MAX_CORNER_PTS              8
#define OPT_DEFAULT_PTS_PER_1000_UNITS          6.0f
#define OPT_DEFAULT_BLANK_SAMPLES               16
#define OPT_DEFAULT_MAX_PTS_PER_FRAME           1010
// Not mirrored in OptimizerLiveConfig above (see the struct's own header
// comment) -- this is optimizer::OptimizerConfig::galvo_kpps' only default,
// used when a caller constructs an OptimizerConfig directly instead of
// through configFromLive(), which always overwrites it with the live
// gProjection.galvo_kpps.
#define OPT_DEFAULT_GALVO_KPPS                  30
#define OPT_DEFAULT_MIN_BLANK_SAMPLES           6
#define OPT_DEFAULT_BLANK_PTS_PER_1000_UNITS    8.0f
#define OPT_DEFAULT_MIN_INTERIOR_PTS_PER_SEG    8
#define OPT_DEFAULT_STAGE1_BLANK_TARGET         16
// RESAMPLE STAGE (Phase 2): constant point spacing. When enabled, interior
// point count for an edge is length / resample_spacing_units instead of
// length/1000 * pts_per_1000_units -- absolute, length-independent spacing
// so a 100-unit and a 1000-unit edge get the same points-per-unit density.
// Disabled by default -> edgeInteriorCount() keeps using pts_per_1000_units,
// so output stays byte-identical to the pre-resample optimizer.
#define OPT_DEFAULT_RESAMPLE_ENABLED             false
#define OPT_DEFAULT_RESAMPLE_SPACING_UNITS       160.0f
// CURVATURE-ADAPTIVE RESAMPLE (P11b): a modifier on the resample stage above.
// The constant resample spacing is a floor of density that ignores shape --
// a tight arc and a straight run get the same points-per-unit. When enabled,
// the local spacing is scaled down where the polyline actually bends: the
// discrete turn angle at an edge's endpoints (second difference of the vertex
// sequence, radians 0..PI) is read as a curvature proxy, and the effective
// spacing becomes resample_spacing_units / (1 + curvature_gain * turnAngle),
// clamped to [min_spacing_units, max_spacing_units]. A straight run (turn ~0)
// keeps the base spacing -> byte-identical to the plain resample result there;
// only curved regions densify. Feeds the SAME planSegment/budget/Stage-1
// path, so curvature density scales down under max_pts_per_frame like
// everything else. Brings continuous curve_patterns.cpp geometry (no discrete
// corners) into the optimizer via a per-turn-angle density instead of
// corner_angle_deg. Disabled by default -> resample stage unchanged.
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

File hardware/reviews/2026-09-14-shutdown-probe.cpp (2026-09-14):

// Diagnostic snapshot for the 2026-09-14 shutdown-boundary review.
// Reproduces UNSAFE baseline decisions; passing is NOT a safety acceptance gate.
// allOk() and emergencyStop() are copied verbatim from b4385e3 safety.cpp.
// GPIO, health and logging are host stubs; no firmware/RTOS/electrical test.
#include <atomic>
#include <cassert>
#include <iostream>

struct State {
    std::atomic<bool> estop_ok{true}, scanfail_ok{true}, laser_armed{true};
} gState;
struct Config { bool safety_override = false; } gConfig;
static volatile bool s_user_arm_request = true;
static bool wd = true, subs = true;
static int enable_output = 1, estop_input = 1;
constexpr int PIN_LASER_ENABLE = 38, PIN_ESTOP = 47, LOW = 0, HIGH = 1;
bool watchdogOk() { return wd; }
bool subsystemsOk() { return subs; }
void digitalWrite(int pin, int value) {
    assert(pin == PIN_LASER_ENABLE);
    enable_output = value;
}
int digitalRead(int pin) {
    assert(pin == PIN_ESTOP);
    return estop_input;
}
#define ESP_LOGW(...) ((void)0)
#define LOG_W(...) ((void)0)

bool allOk() {
    if (gConfig.safety_override) {
        return s_user_arm_request;  // bypass HW/watchdog/subsystem checks
    }
    return gState.estop_ok.load() &&
           gState.scanfail_ok.load() &&
           watchdogOk() &&
           subsystemsOk() &&
           s_user_arm_request;
}

void emergencyStop() {
    // v4.5.15: do not revoke ARM when safety_override is active —
    // otherwise every pushFrame timeout triggers a permanent DISARM
    // that the user cannot recover from without a page reload.
    if (!gConfig.safety_override) {
        s_user_arm_request = false;
    }
    digitalWrite(PIN_LASER_ENABLE, LOW);
    gState.laser_armed.store(false);
    LOG_W(logbuf::CAT_SAFETY, "EMERGENCY STOP");
    ESP_LOGW(TAG, "Emergency stop triggered");
}

void sampleEstop() {
    gState.estop_ok.store(digitalRead(PIN_ESTOP) == HIGH);
}

int main() {
    for (bool override_value : {false, true}) {
        for (int fault = 0; fault < 4; ++fault) {
            gConfig.safety_override = override_value;
            s_user_arm_request = true;
            gState.estop_ok = (fault != 0);
            gState.scanfail_ok = (fault != 1);
            wd = (fault != 2);
            subs = (fault != 3);
            assert(allOk() == override_value);
            std::cout << "fault " << fault << " override " << override_value
                      << " enable_decision " << allOk();
            // The task's input/decision path does not clear the ARM request.
            gState.estop_ok = true;
            gState.scanfail_ok = true;
            wd = subs = true;
            assert(s_user_arm_request && allOk());
            std::cout << " after_fault_clears " << allOk() << "\n";
        }
        s_user_arm_request = false;
        assert(!allOk());
        s_user_arm_request = true;
        gState.laser_armed = true;
        enable_output = HIGH;
        emergencyStop();
        assert(enable_output == LOW && !gState.laser_armed.load());
        assert(s_user_arm_request == override_value);
        assert(allOk() == override_value);
        std::cout << "stop override " << override_value
                  << " immediate_output " << enable_output
                  << " arm_request " << s_user_arm_request
                  << " next_decision " << allOk() << "\n";
    }
    estop_input = HIGH;
    sampleEstop();
    assert(gState.estop_ok);
    estop_input = LOW;
    sampleEstop();
    assert(!gState.estop_ok);
    std::cout << "estop: HIGH accepted; LOW rejected\n";
}

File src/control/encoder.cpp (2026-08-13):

#include "encoder.h"
#include "pinmap.h"
#include "config.h"
#include "patterns/calib_patterns.h"
#include "patterns/preset_patterns.h"
#include "patterns/pattern_engine.h"
#include "storage/sd_card.h"
#include "ilda/ilda_player.h"
#include <Arduino.h>
#include <esp_log.h>

namespace encoder {

static const char* TAG = "enc";

enum EncoderMode : uint8_t {
    MODE_PRESET  = 0,   // Drehen = Preset switch
    MODE_DIMMER  = 1,   // Drehen = Master-Dimmer
    MODE_ILDA    = 2,   // rotate = ILDA file
    MODE_CALIB   = 3,   // Drehen = calibration-Pattern
    MODE_COUNT   = 4
};

static const char* MODE_NAMES[MODE_COUNT] = {
    "Preset", "Dimmer", "ILDA", "Calib."
};

static volatile int32_t s_pos      = 0;
static volatile int32_t s_last_pos = 0;
static EncoderMode       s_mode    = MODE_PRESET;

// Entprell-State
static uint32_t s_btn_pressed_ms   = 0;
static bool     s_btn_was_pressed  = false;
static uint32_t s_last_click_ms    = 0;
static uint8_t  s_click_count      = 0;

static volatile int8_t s_enc_a_last = 0;

static void IRAM_ATTR enc_isr(void*) {
    int8_t a = digitalRead(PIN_ENC_A);
    int8_t b = digitalRead(PIN_ENC_B);
    if (a != s_enc_a_last) {
        s_pos += (a == b) ? 1 : -1;
        s_enc_a_last = a;
    }
}

void init() {
    pinMode(PIN_ENC_A,   INPUT_PULLUP);
    pinMode(PIN_ENC_B,   INPUT_PULLUP);
    pinMode(PIN_ENC_BTN, INPUT_PULLUP);  // GPIO41 free — encoder button re-enabled
    s_enc_a_last = digitalRead(PIN_ENC_A);
    attachInterruptArg(PIN_ENC_A, enc_isr, nullptr, CHANGE);
    ESP_LOGI(TAG, "Encor init GPIO A=%d B=%d BTN=%d",
             PIN_ENC_A, PIN_ENC_B, PIN_ENC_BTN);
}

static void applyDelta(int32_t delta) {
    if (delta == 0) return;
    switch (s_mode) {
        case MODE_PRESET: {
            // cycle preset index, activate via pattern engine
            static uint8_t enc_preset = 0;
            enc_preset = (uint8_t)constrain((int)enc_preset + delta, 0, presets::PRESET_COUNT - 1);
            gLivePreset.pattern_idx = enc_preset;
            patterns::setPreset(presets::presetFromIndex(enc_preset));
            break;
        }
        case MODE_DIMMER: {
            // Target ui_master_dimmer, not master_dimmer directly --
            // pattern_engine's resolveMasterDimmer() overwrites master_dimmer
            // from DMX/ui_master_dimmer every tick, which was stomping the
            // encoder's writes and made the standalone (no-DMX) front-panel
            // knob non-functional. ui_master_dimmer is the same knob the
            // WebUI drives via /api/ui-control.
            int d = (int)gState.ui_master_dimmer.load() + delta * 5;
            gState.ui_master_dimmer.store((uint8_t)constrain(d, 0, 255));
            break;
        }
        case MODE_ILDA:
            // next/previous ILDA file
            if (sd_card::fileCount() > 0) {
                int idx = (int)ilda::gILDA.file_idx + delta;
                idx = ((idx % (int)sd_card::fileCount()) + sd_card::fileCount())
                      % sd_card::fileCount();
                ilda::loadFile((uint8_t)idx);
            }
            break;
        case MODE_CALIB: {
            int idx = (int)gState.calib_idx + delta;
            idx = ((idx % calib_patterns::CALIB_PATTERN_COUNT)
                   + calib_patterns::CALIB_PATTERN_COUNT)
                  % calib_patterns::CALIB_PATTERN_COUNT;
            gState.calib_idx = (uint8_t)idx;
            gState.calib_active = true;
            break;
        }
        default: break;
    }
}
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

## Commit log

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2026-06-15 Added Random hostname Generation based on MAC address (fe: galvos-AA11BB) Fix double-increment of hb_count by using separate counter for subsystem heartbeat subsystemHeartbeat() was never called incr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
    [config.h, galvo_out.cpp, main.cpp]
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2026-06-16 fix(safety): emergencyStop() preserves ARM when safety_override active; fix curve/DMX push rate exceeding galvoTask drain capacity
    [safety.cpp]
2026-06-16 fix: emergencyStop preserves ARM under safety_override; add ring buffer memory barriers (RELEASE/ACQUIRE) to fix corrupt frames on dual-core; reduce curves/DMX push rate below galvoTask drain capacity
    [galvo_out.cpp, safety.cpp]
2026-06-16 fix: initialize gOverride DMX values to sane defaults (hmove/vmove=128=center, size=128) — zero defaults caused -12800px offset collapsing all presets to single point
    [config.h]
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2026-06-16 fix(galvo): replay current frame on underrun instead of blanking — eliminates 37ms laser-off gap between pattern_engine pushes causing visible flicker and single-point dropout
    [galvo_out.cpp]
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2026-06-16 debug: add galvoTask stack high-water-mark to GV log — diagnose potential silent stack overflow crash
    [galvo_out.cpp]
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2026-06-17 debug: log first+last DAC point per second in galvoTask to trace coordinate corruption during projection failure
    [galvo_out.cpp]
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2026-06-18 fix(presets): fix geometry rendering, DISPATCH off-by-one, remove debug logs
    - ngon(): interpolate per side (4-gon: 20 steps, 5-6: 14, 7+: 10) — fixes
    Square/Triangle/Pentagon/Hexagon/Octagon projecting as circles
    - star(): interpolate per segment (16 steps) — fixes Star4-8 projecting as dots
    - line(): add closing blank after last point — fixes retrace artifacts on
    Cross+, Grid 3x3, and all multi-segment line presets
    - wf(): increase points per 3D edge 14->28 — fixes Cube/3D presets showing
    curved lines instead of straight edges
    - DISPATCH: insert p83 (Disco Ball) at index 64; move p100 (Countdown) before
    Vehicles; drop orphan p99 — fixes all presets from index 64 onwards s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
    [galvo_out.cpp]
2026-06-18 fix(galvo): blank laser before DAC write to eliminate retrace artifacts
    rgbOff() is now called before writeDAC8562() on blank points, giving
    the laser a full tick to extinguish before the galvo moves. Previously
    the laser stayed on for one tick during the galvo transit, causing
    visible retrace lines between segments.
    Also removes the near-rail debug log (already scheduled for v4.5.24).
    [galvo_out.cpp]
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2026-06-18 fix(galvo): use gpio_set_level for instant laser blanking
    ledcWrite(255) waits up to one PWM cycle (20us@50kHz) before the pin
    goes HIGH. gpio_set_level() is immediate. Re-attaches LEDC via
    ledcAttachPin() in rgbWrite() when needed. Eliminates residual
    laser-on time during blank galvo transits.
    Left LEDC_FREQ_RGB to 100kHz (50kHz previous)
    [galvo_out.cpp]
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2026-06-19 fix: laser-on-boot + residual blanking via LEDC attach/detach race
    rgbOff() now detaches LEDC before driving GPIO HIGH; setup() no
    longer pre-attaches LEDC, preventing its initial LOW duty from
    overwriting the safe HIGH state before first rgbWrite().
    [galvo_out.cpp, pinmap.h]
2026-06-19 fix: remove per-point LEDC attach/detach causing dotted-line flicker
    rgbOff()/rgbWrite() now only call ledcWrite() — LEDC stays permanently
    attached after a single setup() call. Previous fix re-attached LEDC on
    every blank/unblank transition, which at 15-30kpps caused visible
    flicker on patterns with frequent segment jumps (wireframes, multi-
    segment presets). Boot-off behavior preserved: GPIO HIGH set before
    attach, rgbOff() drives duty=255 immediately after attach.
    [galvo_out.cpp]
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2026-06-20 fix: point_optimizer Stage1/Stage2 order regression (no visible edges)
    A previous patch pass left the interior-density clamp (Stage 2) physically
    above the blank-samples clamp (Stage 1) in optimize(), instead of after
    it. Stage 2 computed available budget for interior points using the
    INFLATED default blank_overhead (40 samples/run), driving
    pts_per_1000_units to its 0.1 floor before Stage 1 ever got a chance to
    shrink blanking. Result: wireframe presets (Cube/Octahedron/Tetrahedron)
    rendered as isolated corner dots with no connecting line.
    Confirmed against hardware logs: blank-point counts matched simulation
    exactly (Stage 1's blank-shrink logic was already correct), lit-point
    counts were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
    [config.h]
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2026-06-21 feat: WebUI live-tunable Point Optimizer settings
    Add all 9 OptimizerConfig parameters as sliders in Config tab:
    corner_angle_deg, min/max_corner_pts, pts_per_1000_units,
    min_segment_pts, blank_samples, max_pts_per_frame, min_blank_samples,
    blank_pts_per_1000_units, min_interior_pts_per_segment.
    Backend: OptimizerLiveConfig (config.h) extended with previously-missing
    fields; persisted to NVS (persistConfig/loadConfig); exposed via
    GET /api/config; new POST /api/optimizer-live (apply immediately, no
    persist, for slider dragging) and POST /api/optimizer-save (persist).
    liveOptimizerConfig() (preset_patterns.cpp) now copies all 9 fields
    instead of 6 -- the missing 4 meant max_pts_per_frame et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
    [config.h, main.cpp]
2026-06-21 feat: WebUI stage1_blank_target -- restore blank density slider effect
    Stage 1 (budget clamp) collapsed blank_samples straight to
    min_blank_samples (8) whenever triggered, leaving emitBlankJump() zero
    range to scale into -- every jump got clamped to the same single value,
    silently defeating blank_pts_per_1000_units (the WebUI slider had no
    visible effect on Cube/Octahedron).
    Add stage1_blank_target (default 20, WebUI-tunable): Stage 1 now reduces
    blank_samples toward this target first, only falling back to the hard
    min_blank_samples floor if the target still doesn't fit the budget.
    Wired through config.h, main.cpp boot-load, web_ui.cpp (persist/GET/
    optimizer-live), preset_patterns.cpp live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
    [config.h, main.cpp]
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2026-06-22 fix(galvo_out): hold DAC position for one tick on lit→blank transition to absorb LEDC/6N137 turn-off latency (corner hook fix)
    [galvo_out.cpp]
2026-06-22 Commit: fix(galvo_out): 2-tick DAC hold on lit→blank transition, absorbs LEDC 50kHz turn-off latency (corner hook fix)
    [galvo_out.cpp]
2026-06-22 fix(optimizer): carve galvo settle ticks from blank budget to fix open corners; debug: force red-only output
    [galvo_out.cpp]
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2026-06-23 fix(text): LOCK_STATE around gTextConfig read/write web_ui.cpp: wrap /api/text handler writes in LOCK_STATE() pattern_engine.cpp: snapshot gTextConfig under LOCK_STATE() before render to prevent dual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
    [config.h]
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2026-06-23 fix: preset index mismatch, countdown timer, text render & starfield bugs
    UI/firmware preset index alignment:
    - PRESET_DEFS: vehicles 92-99 -> 93-100, countdown 100 -> 92
    - PRESET_PARAM_HINTS + PRESET_RENDER_FNS (index.html, preview.html)
    remapped to match DISPATCH (starfield 91, countdown 92)
    - timerSet() activatePreset(100) -> 92; p100 never ran, so
    countdown_timer::tick() never fired and display stuck at 00:00
    text_renderer:
    - bold pass: unify EN sentinel detection (sx==EN), add n<max guard
    - TANIM_ROTATE: rotate around text centroid, not origin (was orbiting)
    - TANIM_TYPEWRITER: cap strncpy length to buffer
    - TANIM_STARWARS: incremental cx2 (O(n^3)->O(n)/frame) + inter-glyph blank
    -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
    [galvo_out.cpp, main.cpp]
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2026-06-24 Fix galvoTask snapshot called per-point instead of per-frame
    updateSnapshot() ran every tick (semaphore + 64-bit div), overrunning
    the 22us/point budget at 45kpps. Galvo could not reach target rate,
    ring buffer overflowed, caused flicker. Now snapshots once per frame
    at s_point_idx==0.
    [galvo_out.cpp]
2026-06-25 fix(webui): add missing DMX CH23-25 (col anim) to override panel refactor: OPT_DEFAULT_* macros as single source of truth for optimizer defaults config: set optimizer defaults for 45kpps / 750 pts sw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
    [config.h]
2026-06-25 perf: writeDAC8562XY() acquires SPI bus once for both channels, halves mutex overhead at 45kpps fix display issue in index.html
    [galvo_out.cpp]
2026-06-25 fix: remove duplicate DAC writes in lit path (merge artifact from writeDAC8562XY migration)
    [galvo_out.cpp]
2026-06-25 fix: writeDAC8562XY W0 word order — no byte swap needed, SPI2 sends MSB-first
    [galvo_out.cpp]
2026-06-25 fix: ESP32-S3 SPI requires cmd.update latch before cmd.usr; poll trans_done for completion
    [galvo_out.cpp]
2026-06-25 Commit message: fix: remove IDF CS control for DAC8562 (spics_io_num=-1), CS now fully manual via GPIO W1TS/W1TC
    [galvo_out.cpp]
2026-06-25 fix: ESP32-S3 SPI raw transfers — USER reg, UPDATE latch, manual CS on all paths
    [galvo_out.cpp]
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2026-06-28 fix: disable SPI2 DMA_TX_ENA for raw W0 CPU-mode transfers — DMA bypasses W0 register
    [galvo_out.cpp]
2026-06-28 fix: poll cmd.USR instead of TRANS_DONE — TRANS_DONE unreliable in CPU-mode with DMA bus
    [galvo_out.cpp]
2026-06-28 feat: raw SPI2 register access for DAC writes, ~37% throughput gain (22→30 kpps)
    Replace spi_device_polling_transmit() with direct SPI2 hardware register
    access in writeDAC8562XY(). Eliminates IDF mutex/hook overhead per call.
    Key findings from oscilloscope debug (branch test/raw-spi-registers):
    - SPI_DMA_CH_AUTO on bus init causes W0 to be ignored (DMA bypasses W0)
    -> fixed by clearing DMA_TX_ENA (SPI_DMA_CONF_REG bit28) once at startup
    - TRANS_DONE flag unreliable in CPU-mode with DMA bus
    -> fixed by polling cmd.USR bit24 instead
    - ESP32-S3 SPI2 W0 sends LSB-first, not MSB-first as assumed
    -> fixed word packing: LSB in W0[23:16], MSB in W0[7:0]
    - cmd.UPDATE latch required before c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
    [galvo_out.cpp]
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2026-07-01 fix: park blanked at loop start to prevent wraparound bleed line in zone_outline
    [calib_patterns.cpp]
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2026-07-03 fix: map DMX CH23-25 to gLivePreset.col_anim_type/seq/speed fix: encoder MODE_PRESET now activates preset via patterns::setPreset() feat: compute gamma LUT at runtime from gamma_val instead of fixed 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
    [encoder.cpp, galvo_out.cpp, galvo_out.h]
2026-07-03 fix: guard gLivePreset rotation angles with mtx::state fix: snapshot gZone under mtx::zone to fix core0/core1 clip race
    [galvo_out.cpp]
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2026-07-03 feat: add Paint by Finger tab (freehand + shapes, segment color anim, 3-axis rotation)
    - new WebUI tab: canvas draw (pointer-based), Rect/Triangle/Circle/Line
    shape tools with drag-to-create and draggable handles, quick color
    swatches + custom picker, live throttled projection or paint-first
    then Project
    - new pattern mode (paint_patterns.h/.cpp): generic vertex-path strokes
    fed through the existing point_optimizer, reuses the Preset
    color-animation engine (Segment mode) and 3-axis auto-rotation
    (gLivePreset), guarded by dedicated mtx::paint mutex (same
    write-tear fix pattern as gZone)
    - new API: GET /api/paint, POST /api/paint/set|clear|off
    - setPreset()/setCurve() now also cl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
    [config.h, main.cpp]
2026-07-04 fix: increase pattern task stack, add stack margin watchdog
    - pattern task stack 8192->12288 after stack-canary crash (task confirmed via panic message; exact allocation unconfirmed)
    - add stack_mon module: warns once per task when free stack drops below 1024B
    - wire stack_mon::watch() into startTask(), stack_mon::update() into web_ui task loop
    [main.cpp]
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2026-07-06 debug: add heap checkpoint logging through setup() to isolate the network-crash source
    [main.cpp]
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2026-07-06 feat(pointsOnlyMode): independent fade-in/out with hard-cut toggle and spatial wipe direction
    Replace shared points_fade_ms/points_stagger with points_fade_in_ms,
    points_fade_out_ms, points_fade_in_on, points_fade_out_on, points_fade_dir.
    fadeWipePosition() maps each dot to a normalized coordinate along the
    selected axis (in/out, left/right, top/bottom), driving a spatial sweep
    instead of perimeter-order stagger. Fade toggles off = instant hard
    on/off, no ramp.
    [config.h]
2026-07-06 feat(pointsOnlyMode): add Static Mode, translate direction labels, fix dead reset refs
    points_static_on bypasses fade calc, full brightness dwell.
    Enum comments + UI option labels: German -> English.
    resetLiveControls() still referenced removed lv-pm-fade/lv-pm-stagger
    elements from prior fade-in/out refactor — fixed.
    [config.h]
2026-07-06 feat(autoScale): speed-driven size oscillation with 3 loop modes
    New autoscaleSpeed (0-100%, 0=off) and autoscaleMode (small-big-small,
    small-big, big-small) drive computeAutoScaleSize(), overriding size_val
    before presets::generate(). Reuses DMX_AUTO_SCALE channel intent
    ("Automatic size pulsing") documented but never wired up.
    [config.h]
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2026-07-07 fix: reduce ILDA calib preset circle resolution to fit flicker budget
    - CPTS 80 -> 32 in ilda_test() (calib_patterns.cpp)
    - frame point count 353 -> 305, within 310pts/frame safe limit
    - resolves faint/flickering circle at full master dimmer
    [calib_patterns.cpp]
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2026-07-09 feat: eliminate rotation seam across all rotating presets
    - csweep() continuous-sweep (#2): seam=0/C1 for 2pi-periodic curves
    p00,p22,p23,p24,p26,p27 -- zero state, zero budget, visual unchanged
    - generate() (presets+calib): cross-frame eased blank bridge (#4) for all
    non-continuous rotating presets (Lissajous, matrix-rotated, harmonic,
    multi-subpath) + calib rainbow/saturation_wheel; on-demand, tail-evicted,
    no fixed reservation; skipped at speed 0 and for #2 presets
    - verified: #2 boundary jump 0.000000 units to ph=0xFFFFFF; #4 br[]<=100 pts
    [calib_patterns.cpp]
2026-07-09 Add UI/heap failsafe: relay drop on stale /api/state poll (3s), esp_restart() after 10s or heap fragmentation
    [config.h, safety.cpp]
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2026-07-09 Replace static corner/density/blank comparison SVGs with animated crossfade previews
    Point Optimizer now shows the actual bad/good effect for each parameter
    (corner sharpness, line density, frame flicker, blank-jump cleanliness,
    ringing) as a looping CSS crossfade instead of static side-by-side SVGs.
    Reuses the existing hand-drawn paths as the two crossfade states; no new
    illustration work for corner/density/blank. Adds 'flicker' and 'ringing'
    families for Frame budget and Ringing compensation, which had no prior
    static comparison. Dead .opt-visual* CSS removed.
    [config.h]
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2026-07-10 refactor(patterns): split Mirror effect from Kaleidoscope
    mirror_x/mirror_y bools -> mirror_mode enum (Off/X/Y/Radial4), own UI
    cell below Kaleidoscope, button group matching Paint-by-Finger's mirror
    brush. Extract shared N-fold rotational-copy core (applyRadialCopy) used
    by both applyKaleidoscope() (configurable segments + alternating mirror)
    and applyMirror()'s Radial4 case (fixed 4 segments, no mirror -- same as
    Paint's radial4).
    - config.h: MirrorMode enum, mirror_mode field replaces mirror_x/y
    - pattern_engine.cpp: applyRadialCopy() extracted, applyMirror() added
    - web_ui.cpp: /api/preset-live mirror_mode parsing
    - index.html: Mirror button-group cell, setLiveMirror()
    [config.h]
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2026-07-11 Fix open 3D wireframe corners; rework Random Points as real flicker scene
    - buildWfChains(): continue chain through any vertex with an unused
    edge, not just degree==2. Polyhedra have min degree 3, so every
    edge was previously isolated into its own blank-jumped segment --
    no corner ever actually closed. Cube -> 2 closed squares + 4 struts,
    Pyramid -> 1 closed base + 2 apex chains, Octahedron -> 3 closed
    loops, Tetrahedron -> 1 closed + 2 open (down from 12/8/12/6
    disconnected edges).
    - p106 Random Points: was a static rotating cloud. Now up to 14
    independent slots each run a real-time appear/hold/disappear/idle
    cycle, desynced per slot, so visible count varies 0..Amount.
    Pos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
    [config.h]
2026-07-12 fix(calib): render fill patterns as short color strokes
    White Balance, Step Ramp and Color Temperature used area/full-width
    fills the galvo cannot draw. Replace with short strokes (minimal DAC
    travel) that still fit the point budget while staying identifiable.
    [calib_patterns.cpp]
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2026-07-12 feat: add Resample stage (constant point spacing) — Phase 2
    Interior point count switches to length/resample_spacing_units when
    resample_enabled, giving absolute length-independent spacing (uniform
    galvo velocity across a shape) instead of length-proportional density.
    Disabled by default -> byte-identical output. cornerSeverity nominalStep
    is made resample-aware so speedT compares against the correct reference.
    Changed:
    - point_optimizer.h/.cpp: resample in edgeInteriorCount(); config fields
    - config.h: OPT_DEFAULT_RESAMPLE_* macros; OptimizerLiveConfig fields
    - preset/calib/paint_patterns.cpp: liveOptimizerConfig() mapping
    - web_ui.cpp: NVS persist, /api/config, /api/optimizer-live parse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
    [calib_patterns.cpp, config.h, main.cpp]
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2026-07-12 feat: wire live Z-rotation into optimizer transform stage (Phase 3)
    Publish the affine part (in-plane Z rotation) of the live controls into
    optimizer::gLiveTransform once per frame, before the active generate()
    call. Each optimizer-fed path's OptimizerConfig now carries this via
    cfg.transform, so corner detection and resampling run on rotated geometry
    instead of the old post-optimizer point-space pass.
    - point_optimizer.h: add makeTransform(), extern gLiveTransform, Phase 3 docs
    - main.cpp: define optimizer::gLiveTransform (identity default)
    - pattern_engine.cpp: publish transform before preset/paint generate();
    remove inline Z-rotation; per-frame identity reset before priority chain;
    Y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
    [calib_patterns.cpp, main.cpp]
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2026-07-13 feat: add sample-rate autotune (binary search against live pattern, avoids ring buffer overflow)
    [galvo_out.cpp, galvo_out.h]
2026-07-13 refactor: type-safe Preset selection via enum class
    Replace int8_t preset index with enum class Preset (105 named
    values + None sentinel). Bounds check centralized in
    presets::presetFromIndex(), called at both external entry points
    (WebUI JSON, encoder) instead of inside setPreset(). Internal
    DISPATCH[]/generate() dispatch stays uint8_t (unrelated to
    selection safety).
    [encoder.cpp]
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2026-07-13 fix(config): restore ringing/vel/accel-clamp settings from NVS on boot
    loadConfig() in main.cpp never read back ringing_comp_enabled,
    ring_freq_hz, ring_damping_ratio, vel_clamp_enabled, max_step_units,
    accel_clamp_enabled, max_accel_units -- persistConfig() writes these
    keys (opt_rngen/opt_rngfq/opt_rngdr/opt_vcen/opt_vcstp/opt_acen/
    opt_acmax) but loadConfig() stopped after opt_rssp. Struct defaults
    (false) won the race on every reboot, silently discarding UI toggles.
    [main.cpp]
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2026-07-14 feat(calib): add per-channel RGB visibility threshold mapping
    Add thresh_r/g/b ("Basiswert") to RuntimeConfig, persisted via NVS.
    Below this per-channel PWM duty the laser driver emits no visible
    light; mapVisibleRange() in galvo_out.cpp remaps the logical 0-255
    color range onto [threshold..255] so 0-100% brightness always spans
    the actually visible output instead of wasting range on a dead zone.
    Applied in rgbWrite() after gamma correction, right before ledcWrite().
    - config.h: thresh_r/g/b fields, defaults 143/144/169
    - galvo_out.cpp: mapVisibleRange(), rgbWrite() takes thresholds as
    params (called before GalvoSnapshot is declared), GalvoSnapshot +
    updateSnapshot() carry thresh_r/g/b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
    [config.h, galvo_out.cpp, main.cpp]
2026-07-14 feat(calib): add dedicated Basiswert test-beam (Start/Stop)
    The White Balance pattern always drives channels at raw 255, and
    mapVisibleRange(255, x) == 255 for any threshold -- so the Base R/G/B
    sliders had no visible effect while testing against it.
    Add a dedicated priority branch in galvoTask() for threshold
    calibration: a static beam at a fixed minimal logical level (1),
    with gain, gamma and the master dimmer all bypassed. rgbWrite() gains
    a skip_gamma param so mapVisibleRange() sees that raw level directly,
    making PWM duty track the configured threshold almost 1:1.
    - config.h: calib_thresh_test, calib_thresh_ch
    - galvo_out.cpp: new branch ahead of s_hw_debug_active; rgbWrite()
    takes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
    [config.h, galvo_out.cpp]
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2026-07-14 fix(galvo_out): use max(master_dimmer, ui_master_dimmer) for dimEff
    galvoTask used only master_dimmer for dimEff, leaving it 0 when DMX
    is inactive (default). ui_master_dimmer kept pattern_engine pushing
    frames through (guard at line 911 checks either), but galvoTask
    multiplied all RGB values by dimEff=0, making gain and threshold
    sliders appear to have no effect on calib patterns.
    Fix mirrors the existing pattern_engine guard: take whichever dimmer
    is higher, consistent with "either non-zero is sufficient to show
    output" semantics.
    [galvo_out.cpp]
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2026-07-14 refactor(calib): replace color patterns with optimizer calibration suite
    Remove 10 color/gamma patterns from calib tab (Gamma Ramp, White Balance,
    Rainbow, Step Ramp, Channel Separation, Saturation Wheel, Focus Test,
    Scan Linearity, Corner Test, Color Temperature). Add 4 optimizer test
    patterns that run through the full liveOptimizerConfig() pipeline:
    - idx 7: Corner Sweep → corner_angle_deg / min/max_corner_pts
    - idx 8: Density Ramp → pts_per_1000_units / resample stage
    - idx 9: Jump Ring Test → blank_samples / ringing_comp (Pillar 2/3)
    - idx 10: Vel/Accel Test → max_step_units / max_accel_units
    CALIB_PATTERN_COUNT: 17→11. PRESET_COUNT: 111→107 (opt patterns moved
    from Pre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
    [calib_patterns.cpp, calib_patterns.h]
2026-07-14 fix(calib): remove double gamma in colorOut; gain sliders now effective
    colorOut() applied applyGamma() before storing into LaserPoint.r/g/b.
    galvo_out.cpp:rgbWrite() then applied it a second time. The squared
    gamma curve crushed mid/low values below thresh_r/g/b, making
    gain_r/g/b sliders appear to have no effect on all calib patterns.
    Fix: colorOut() now scales brightness only; rgbWrite() is sole gamma
    authority, consistent with every other pattern source.
    [calib_patterns.cpp]
2026-07-14 fix(calib): vel clamp ineffective on Velocity & Accel Test pattern
    opt_vel_accel routed both segments through a single optimize() call
    with pts_per_1000_units=4, producing ~317 interpolated points on the
    diagonal (step ~249 units). max_step_units=2000 never triggered.
    Split into two separate optimize() calls: diagonal uses cfgDiag with
    pts_per_1000_units=0 / min_segment_pts=2 / accel_clamp_enabled=false
    so only the two raw endpoints are emitted (~79k unit step); star uses
    the full live config. clampScannerLimits() now subdivides the diagonal
    visibly when vel_clamp is enabled.
    Lower OPT_DEFAULT_MAX_STEP_UNITS 2000→200 and tighten UI slider range
    (10–500, step 5) to match the actual effe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
    [calib_patterns.cpp, config.h]
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

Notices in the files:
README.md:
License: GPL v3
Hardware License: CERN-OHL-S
